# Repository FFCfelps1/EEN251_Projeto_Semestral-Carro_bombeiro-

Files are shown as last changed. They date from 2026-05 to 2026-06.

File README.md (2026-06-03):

# 🚒 EEN251 — Carro de Bombeiro Teleoprado

> **Disciplina:** EEN251 — Projeto Integrador de Sistemas Embarcados  
> **Semestre:** 1º Semestre / 2026  
> **Data de início:** Março de 2026

---

## Sumário

1. [Integrantes e Responsabilidades](#1-integrantes-e-responsabilidades)
2. [Descrição Geral do Projeto](#2-descrição-geral-do-projeto)
3. [Objetivos](#3-objetivos)
4. [Estrutura do Repositório](#4-estrutura-do-repositório)
5. [Materiais e Componentes](#5-materiais-e-componentes)
6. [Arquitetura do Sistema](#6-arquitetura-do-sistema)
7. [Pinagem e Conexões](#7-pinagem-e-conexões)
8. [Firmware — Descrição e Fluxograma de Estados](#8-firmware--descrição-e-fluxograma-de-estados)
9. [Convenção de Commits](#9-convenção-de-commits)
10. [Política de Tags e Versões](#10-política-de-tags-e-versões)
11. [Cronograma](#11-cronograma)
12. [Orçamento Total Estimado](#12-orçamento-total-estimado)
13. [Referências Bibliográficas](#13-referências-bibliográficas)

---

## 1. Integrantes e Responsabilidades

| Nome | RA | Função Principal |
|---|----|---|
| Felipe Fazio da Costa | 23.00055-4 | Firmware do Receptor (Pico RX) — motores e bomba |
| João Gabriel Fioruci Roberto | 23.00617-0 | Firmware do Transmissor (Pico TX) — controle RF |
| Gabriel Rodrigues Marques | 23.00578-5 | Hardware — montagem do chassi e fiação |
| Fábio Sadao Sato | 22.00984-0 | Integração do sistema e documentação |

---

## Resumo

Este relatório descreve o desenvolvimento de um protótipo de carro de bombeiro teleoprado utilizando microcontroladores Raspberry Pi Pico e comunicação via rádio frequência (NRF24L01). O sistema integra tração 4WD, sistema de combate a incêndio por bomba d'água e monitoramento de nível de reservatório. Foram aplicados conceitos de sistemas embarcados, comunicação sem fio e controle de periféricos via PWM. Os resultados demonstram a eficácia da plataforma RP2040 em aplicações de controle em tempo real e teleoperação robusta.

**Palavras-chave**: Raspberry Pi Pico. NRF24L01. MicroPython. Carro de Bombeiro. Sistemas Embarcados.

## Abstract

This report describes the development of a teleoperated fire truck prototype using Raspberry Pi Pico microcontrollers and radio frequency communication (NRF24L01). The system integrates 4WD traction, a water pump fire suppression system, and reservoir level monitoring. Concepts of embedded systems, wireless communication, and peripheral control via PWM were applied. The results demonstrate the effectiveness of the RP2040 platform in real-time control applications and robust teleoperation.

**Keywords**: Raspberry Pi Pico. NRF24L01. MicroPython. Fire Truck. Embedded Systems.

---

## 2. Descrição Geral do Projeto

O projeto consiste no desenvolvimento de um veículo robótico em escala inspirado em um caminhão de bombeiro, capaz de se locomover de maneira teleoprada por meio de comunicação sem fio RF 2.4 GHz (módulo NRF24L01). O veículo é dotado de tração 4WD com quatro motores DC controlados por dois módulos L298N, uma mini bomba d'água acionável remotamente, e um reservatório de água com sensor de nível que alerta o operador quando a água estiver baixa.

O sistema é dividido em dois blocos principais:

- **Transmissor (controle remoto):** baseado em um Raspberry Pi Pico com joystick analógico, botões e display OLED SSD1306, responsável por capturar os comandos do operador e enviá-los via NRF24L01.
- **Receptor (carro):** baseado em um segundo Raspberry Pi Pico que recebe os pacotes RF, interpreta os comandos e aciona os motores, a bomba e os alertas de nível.

Todo o firmware é desenvolvido em **MicroPython**, aproveitando a plataforma Raspberry Pi Pico (microcontrolador RP2040).

---

## 3. Objetivos

O objetivo geral deste trabalho é projetar e construir um veículo robótico controlado remotamente via radiofrequência, capaz de realizar manobras de locomoção e acionamento de uma bomba d'água, com monitoramento de status em tempo real.

### 3.1 Objetivos Específicos

- Implementação de comunicação bidirecional robusta entre controle e veículo;
- Controle de tração diferencial (tank drive) para quatro motores;
- Sistema de alerta de nível de água com indicadores visuais e sonoros;
- Desenvolvimento de firmware em MicroPython para a plataforma Raspberry Pi Pico.

---

## 4. Estrutura do Repositório

```
EEN251_Projeto_Semestral(Carro_bombeiro)/
│
├── docs/                        # Documentação HTML do projeto
│   ├── index.html               # Página principal (abas: Requisitos + Diagramas)
│   ├── diagrama_blocos.html     # Diagrama de blocos standalone (legado)
│   └── diagrama_blocos.md       # Diagrama de blocos em Markdown
│
├── firmware/                    # Código MicroPython (a ser criado)
│   ├── tx/                      # Firmware do transmissor (Pico TX)
│   │   └── main.py
│   └── rx/                      # Firmware do receptor (Pico RX)
│       └── main.py
│
├── hardware/                    # Arquivos de hardware (a ser criado)
│   ├── esquematico.pdf
│   └── lista_materiais.csv
│
├── index.html                   # Redirecionamento para docs/index.html
└── README.md                    # Este arquivo
```

---

## 5. Materiais e Componentes

| Qtd | Componente | Finalidade | Preço Est. (R$) |
|-----|---|---|:---:|
| 2 | Raspberry Pi Pico (RP2040) | Controlador central — TX e RX | 35,00 cada |
| 4 | Motor DC 3–6 V com caixa de redução (TT Motor) | Tração 4WD do veículo | 8,00 cada |
| 2 | Módulo L298N (ponte H dupla) | Driver de corrente para os motores | 15,00 cada |
| 2 | Módulo NRF24L01 (PA+LNA opcional) | Comunicação RF 2.4 GHz | 12,00 cada |
| 1 | Mini bomba d'água submersa 3–6 V | Jato d'água do caminhão | 18,00 |
| 1 | Módulo relé 5 V (1 canal) | Chaveamento de corrente da bomba | 6,00 |
| 1 | Sensor de nível d'água (resistivo/capacitivo) | Monitorar volume no reservatório | 5,00 |
| 1 | Chassi 4WD em acrílico ou MDF | Estrutura física do veículo | 45,00 |
| 1 | Bateria LiPo 3,7 V 1000 mAh (18650) | Alimentação do transmissor | 25,00 |
| 1 | Pack 2S 18650 (7,4 V ~2000 mAh) | Alimentação principal do carro | 40,00 |
| 1 | Módulo redutor DC-DC (MP1584 ou LM2596) | Regular 7,4 V → 5 V | 8,00 |
| 1 | Joystick analógico duplo eixo (KY-023) | Controle direcional (X/Y) | 12,00 |
| 2 | Push button (6 mm) | Ativar bomba / parada de emergência | 1,00 cada |
| 1 | Reservatório plástico (~100–200 mL) | Tanque de água do caminhão | 10,00 |
| 1 | Protoboard ou PCB de prototipagem | Prototipagem do circuito | 15,00 |
| — | Jumpers, fios, resistores, LEDs, buzzer, suportes | Conexões e indicadores | 20,00 |

**Total estimado: R$ 362,00**

---

## 6. Arquitetura do Sistema

```
[Joystick X/Y + Botões]
        │
        ▼
  Pico TX — leitura ADC/GPIO (~20 ms)
        │
        ▼
  Monta pacote: { vel_esq, vel_dir, bomba, stop }  (6 bytes)
        │
        ▼
  NRF24L01 TX ──[ RF 2,4 GHz · Enhanced ShockBurst ]──▶ NRF24L01 RX
                                                               │
                                               Pico RX — decodifica pacote
                                                               │
                              ┌────────────────┬──────────────┘
                              ▼                ▼              ▼
                       L298N #1           L298N #2        GPIO Relé
                    (Motor 1 e 2)       (Motor 3 e 4)     (Bomba)
```

**Mapeamento Tank Drive:**
```
vel_esq = Y + X
vel_dir = Y − X
```
Onde Y = eixo vertical (avanço/recuo) e X = eixo horizontal (giro). Valores limitados a [−100, +100].

---

## 7. Pinagem e Conexões

### Receptor — Raspberry Pi Pico (RX)

| Pino | GPIO | Periférico | Sinal | Obs. |
|---|:----:|---|---|---|
| GP0 | 0 | L298N | IN1 | Direção Motor Esq |
| GP1 | 1 | L298N | IN2 | Direção Motor Esq |
| GP2 | 2 | L298N | IN3 | Direção Motor Dir |
| GP3 | 3 | L298N | IN4 | Direção Motor Dir |
| GP4 | 4 | NRF24L01 | MISO (SPI0) | Dados entrada |
| GP5 | 7 | NRF24L01 | CSn | Chip Select |
| GP6 | 4 | NRF24L01 | SCK (SPI0) | Clock SPI |
| GP7 | 11 | NRF24L01 | MOSI (SPI0) | Dados saída |
| GP8 | 29 | Relé Bomba | Sinal | Ativa bomba |
| GP9 | 11 | L298N | ENA (PWM) | Vel. Motor Esq |
| GP10 | 12 | L298N | ENB (PWM) | Vel. Motor Dir |
| GP12 | 6 | NRF24L01 | CE | Chip Enable |
| GP13 | 32 | LED Indicador | GPIO OUT | Status sinal |
| GP22 | 34 | Sensor Nível (D) | GPIO IN | Alerta digital |
| GP27 | 31 | Sensor Nível (A) | ADC1 | Leitura analógica |

### Transmissor — Raspberry Pi Pico (TX)

| Pino | GPIO | Periférico | Sinal | Obs. |
|---|:----:|---|---|---|
| GP0 | 0 | Display OLED | I2C SDA | Dados I2C |
| GP1 | 1 | Display OLED | I2C SCL | Clock I2C |
| GP4 | 6 | NRF24L01 | MISO (SPI0) | Dados entrada |
| GP5 | 7 | NRF24L01 | CSn | Chip Select |
| GP6 | 4 | NRF24L01 | SCK (SPI0) | Clock SPI |
| GP7 | 5 | NRF24L01 | MOSI (SPI0) | Dados saída |
| GP9 | 9 | NRF24L01 | CE | Chip Enable |
| GP19 | 19 | Botão Bomba | GPIO IN | Pull-up interno |
| GP26 | 32 | Joystick Y | ADC1 | Eixo vertical |
| GP27 | 31 | Joystick X | ADC0 | Eixo horizontal |

> ⚠️ **Atenção:** O NRF24L01 opera em **3,3 V**. Nunca conecte o VCC ao pino 5V.

---

## 8. Firmware — Descrição e Fluxograma de Estados

### Transmissor (Pico TX) — loop de ~20 ms
1. Lê ADC do joystick (0–65535) → mapeia para −100…+100 com zona morta central.
2. Lê botões (pull-up; 0 = pressionado).
3. Calcula `vel_esq` e `vel_dir` (tank drive).
4. Monta pacote de 6 bytes e transmite via NRF24L01 PTX com ACK.

### Receptor (Pico RX) — duas tarefas cooperativas
- **Tarefa RF (alta prioridade):** aguarda IRQ do NRF24L01, decodifica campos e aplica PWM/GPIO imediatamente.
- **Tarefa Sensor (baixa prioridade):** lê ADC do sensor de nível a cada 500 ms; aciona LED e buzzer se abaixo do limiar.
- **Watchdog:** desliga todos os motores e bomba se nenhum pacote válido chegar em 500 ms (failsafe).

---

## 9. Convenção de Commits

Este projeto adota o padrão **[Conventional Commits](https://www.conventionalcommits.org/)** para manter um histórico claro e geração automática de changelogs.

### Formato

```
<tipo>(<escopo>): <descrição curta>

[corpo opcional — explica o contexto e motivação da mudança]

[rodapé opcional — ex.: Refs #issue, BREAKING CHANGE: ...]
```

### Tipos permitidos

| Tipo | Quando usar |
|---|---|
| `feat` | Nova funcionalidade no firmware ou na documentação |
| `fix` | Correção de bug no firmware ou na lógica do sistema |
| `docs` | Alterações apenas em documentação (README, HTML, Markdown) |
| `style` | Formatação, identação, espaços — sem mudança de lógica |
| `refactor` | Refatoração de código sem adição de feature ou correção de bug |
| `test` | Adição ou modificação de testes |
| `chore` | Tarefas de manutenção: atualizar dependências, configurar ambiente |
| `hw` | Alterações em arquivos de hardware (esquemático, lista de materiais) |
| `perf` | Melhorias de desempenho (ex.: ajuste de PWM, tempo de polling) |

### Escopos sugeridos

| Escopo | Descrição |
|---|---|
| `tx` | Firmware do transmissor |
| `rx` | Firmware do receptor |
| `rf` | Módulo de comunicação NRF24L01 |
| `motor` | Controle de motores / L298N |
| `bomba` | Sistema de bomba e relé |
| `sensor` | Sensor de nível / alertas |
| `docs` | Documentação (HTML, Markdown) |
| `hw` | Hardware e pinagem |
| `ci` | Configurações de CI/CD |

### Exemplos

```
feat(rx): adicionar failsafe com watchdog de 500ms

Se nenhum pacote RF válido for recebido em 500ms, todos os motores
são desligados e a bomba é desativada por segurança.

feat(tx): implementar mapeamento tank drive do joystick

fix(rf): corrigir inicialização do NRF24L01 após reset de hardware

docs(docs): adicionar aba de diagramas de bloco no index.html

hw(rx): atualizar pinagem do L298N #2 para GP16–GP21

chore: adicionar .gitignore para arquivos de ambiente MicroPython

style(tx): formatar indentação e remover espaços extras
```

### Regras gerais

- A **descrição curta** deve estar em **português**, no **imperativo** e sem ponto final.
  - ✅ `feat(rx): adicionar leitura do sensor de nível`
  - ❌ `feat(rx): Adicionei a leitura do sensor de nível.`
- Limite a linha do cabeçalho a **72 caracteres**.
- Use o corpo para explicar **o quê** e **por quê**, não o como.
- Commits com `BREAKING CHANGE:` no rodapé indicam mudanças incompatíveis com versões anteriores.

---

## 10. Política de Tags e Versões

O projeto utiliza **[Semantic Versioning (SemVer)](https://semver.org/)** no formato `vMAJOR.MINOR.PATCH`.

### Regras de versionamento

| Componente | Quando incrementar |
|---|---|
| **MAJOR** | Mudança incompatível com versão anterior — ex.: alteração no formato do pacote RF que quebra compatibilidade TX↔RX |
| **MINOR** | Nova funcionalidade adicionada de forma retrocompatível — ex.: novo campo no pacote, novo modo de operação |
| **PATCH** | Correção de bug retrocompatível — ex.: ajuste de deadzone, correção de inicialização |

### Estrutura de tags

```
v<MAJOR>.<MINOR>.<PATCH>[-<pre-release>]

Exemplos:
  v0.1.0          — primeira entrega funcional (RF + motores)
  v0.2.0          — integração da bomba e sensor de nível
  v0.2.1          — correção de bug no failsafe
  v1.0.0          — sistema validado e aprovado para apresentação
  v1.0.0-rc.1     — release candidate antes da apresentação final
```

### Milestones de versão planejadas

| Tag | Semana | Descrição |
|-----|:---:|---|
| `v0.1.0` | 5–6 | Comunicação RF funcionando — TX envia, RX recebe |
| `v0.2.0` | 7–8 | Controle de motores via PWM funcional |
| `v0.3.0` | 9–10 | Bomba, relé e sensor de nível integrados |
| `v0.4.0` | 11–12 | Sistema integrado com failsafe e watchdog |
| `v1.0.0-rc.1` | 13–14 | Release candidate — ajustes e calibração |
| `v1.0.0` | 15–16 | Versão final — apresentação |

### Como criar uma tag

```bash
# Criar tag anotada (recomendado)
git tag -a v0.1.0 -m "feat: primeira versão funcional da comunicação RF"

# Enviar tag para o repositório remoto
git push origin v0.1.0

# Enviar todas as tags de uma vez
git push origin --tags
```

### Branches

| Branch | Propósito |
|---|---|
| `main` | Código estável e testado — apenas merges via PR |
| `develop` | Branch de integração contínua |
| `feat/<nome>` | Novas funcionalidades — ex.: `feat/sensor-nivel` |
| `fix/<nome>` | Correções de bug — ex.: `fix/failsafe-timeout` |
| `hw/<nome>` | Alterações de hardware — ex.: `hw/esquematico-v2` |
| `docs/<nome>` | Atualizações de documentação |

---

## 11. Cronograma

| Semana | Período | Etapa | Responsável | Status |
|:---:|---|---|---|:---:|
| 1–2 | 11/03 – 22/03 | Levantamento de requisitos, aquisição de componentes | Todos | ⏳ Pendente |
| 3–4 | 23/03 – 05/04 | Montagem do chassi 4WD e fiação dos motores + L298N | [Nome 3] | ⏳ Pendente |
| 5–6 | 06/04 – 19/04 | Configuração e teste da comunicação RF (NRF24L01 + Pico) | [Nome 2] | ⏳ Pendente |
| 7–8 | 20/04 – 03/05 | Firmware do receptor: controle de motores via PWM | [Nome 1] | ⏳ Pendente |
| 9–10 | 04/05 – 17/05 | Integração da bomba d'água, relé e sensor de nível | [Nome 1] | ⏳ Pendente |
| 11–12 | 18/05 – 31/05 | Integração geral do sistema e testes de validação | Todos | ⏳ Pendente |
| 13–14 | 01/06 – 14/06 | Ajustes finais, failsafe, calibração de parâmetros | Todos | ⏳ Pendente |
| 15 | 15/06 – 21/06 | Preparação da apresentação e finalização da documentação | [Nome 4] | ⏳ Pendente |
| 16 | 22/06+ | Apresentação final | Todos | ⏳ Pendente |

---

## 12. Orçamento Total Estimado

| Categoria | Itens | Subtotal (R$) |
|---|---|:---:|
| Microcontroladores | 2× Raspberry Pi Pico | 70,00 |
| Motores e driver | 4× Motor DC + 2× L298N | 62,00 |
| Comunicação RF | 2× NRF24L01 | 24,00 |
| Sistema de água | Bomba + Relé + Sensor + Reservatório | 39,00 |
| Alimentação | 2× Baterias + Regulador DC-DC | 73,00 |
| Estrutura | Chassi 4WD + Protoboard | 60,00 |
| Controle | Joystick + Botões | 14,00 |
| Miscelânea | Jumpers, LEDs, buzzer, fios, resistores | 20,00 |
| **TOTAL** | | **R$ 362,00** |

> Preços estimados com base em valores de mercado nacional (Mercado Livre, Baú da Eletrônica, Robocore) em março de 2026.

---

## 13. Referências Bibliográficas

1. **Raspberry Pi Ltd.** *Raspberry Pi Pico Datasheet*. Disponível em: https://datasheets.raspberrypi.com/pico/pico-datasheet.pdf
2. **Raspberry Pi Ltd.** *RP2040 Datasheet*. Disponível em: https://datasheets.raspberrypi.com/rp2040/rp2040-datasheet.pdf
3. **STMicroelectronics.** *L298N Dual Full-Bridge Driver Datasheet*. Disponível em: https://www.st.com/resource/en/datasheet/l298.pdf
4. **Nordic Semiconductor.** *nRF24L01+ Product Specification v1.0*. Disponível em: https://www.nordicsemi.com/products/nrf24l01
5. **MicroPython Project.** *MicroPython Documentation for RP2*. Disponível em: https://docs.micropython.org/en/latest/rp2/quickref.html
6. **micropython-nrf24l01 Library.** Disponível em: https://github.com/micropython/micropython-lib/tree/master/micropython/drivers/radio/nrf24l01
7. **Conventional Commits Specification v1.0.0.** Disponível em: https://www.conventionalcommits.org/pt-br/v1.0.0/
8. **Semantic Versioning 2.0.0.** Disponível em: https://semver.org/lang/pt-BR/

---

*Documento gerado em 11 de março de 2026.*

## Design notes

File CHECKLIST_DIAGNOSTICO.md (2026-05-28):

## CHECKLIST DE DIAGNÓSTICO - NRF24L01

### 1️⃣ VERIFICAÇÃO FÍSICA DE HARDWARE

- [ ] **Capacitor 10µF conectado?**
  - Entre VCC e GND do NRF24L01
  - ISSO É CRÍTICO! Sem ele, o módulo não funciona bem

- [ ] **Fios conectados corretamente?**
  
  **CONTROLE (Pico 1):**
  ```
  NRF24L01          Pico
  ─────────────────────────
  1  GND      →   GND
  2  VCC      →   3.3V (COM CAPACITOR!)
  3  CE       →   GP9
  4  CSN      →   GP5
  5  SCK      →   GP6
  6  MOSI     →   GP7
  7  MISO     →   GP4
  8  IRQ      →   (não conectar)
  ```
  
  **CARRO (Pico 2):**
  ```
  NRF24L01          Pico
  ─────────────────────────
  1  GND      →   GND
  2  VCC      →   3.3V (COM CAPACITOR!)
  3  CE       →   GP12  ← DIFERENTE!
  4  CSN      →   GP5
  5  SCK      →   GP6
  6  MOSI     →   GP7
  7  MISO     →   GP4
  8  IRQ      →   (não conectar)
  ```

- [ ] **Nenhum fio solto ou mal soldado?**
  - Verifique todas as conexões
  - Use multímetro se necessário

### 2️⃣ TESTES DE SOFTWARE

**Ordem recomendada:**

#### PASSO 1: Teste no CONTROLE
```
1. Copie: diagnostico_completo.py → Pico do CONTROLE
2. Execute (deixe rodando por 10s)
3. Veja a saída no console
```

Se o CONTROLE disser **"Módulo não responde"**:
- ❌ Fiação está errada
- ❌ Capacitor não está conectado
- ❌ Módulo NRF24L01 pode estar quebrado

Se o CONTROLE disser **"Envio com sucesso"**:
- ✅ Modulo está OK
- → Vá para PASSO 2

#### PASSO 2: Teste no CARRO
```
1. Copie: diagnostico_completo.py → Pico do CARRO
2. Execute (deixe aguardando)
3. Rode novamente o CONTROLE
```

Se o CARRO disser **"Nenhuma mensagem recebida"**:
- ❌ Receptor pode ter fiação errada
- ❌ Capacitor não está conectado
- ❌ CE está no pino errado (deve ser GP12!)

Se o CARRO disser **"X mensagens recebidas"**:
- ✅ COMUNICAÇÃO FUNCIONANDO!

### 3️⃣ SE AINDA NÃO FUNCIONAR

**Checklist final:**

- [ ] Você colocou um **capacitor 10µF** entre VCC e GND?
- [ ] O **CE do CARRO está em GP12** (não GP9)?
- [ ] Os **pinos SCK/MOSI/MISO** estão iguais nos dois?
- [ ] Os **endereços são iguais?**
  ```
  ADDR_CONTROLE = bytes([0xE7, 0xE7, 0xE7, 0xE7, 0xE7])
  ADDR_CARRO    = bytes([0xC2, 0xC2, 0xC2, 0xC2, 0xC2])
  ```
- [ ] Os **dois Picos estão no CHANNEL 2?**
- [ ] Você **alimenta os Picos corretamente?** (USB ou 5V externo)
- [ ] O **NRF24L01 está alimentado em 3.3V**? (não 5V!)

### 4️⃣ RESULTADO ESPERADO

**CONTROLE console:**
```
[6] TESTE DE ENVIO...
  Enviando: [50, 30, 1, 0]
  ✓ ENVIO COM SUCESSO!
```

**CARRO console:**
```
[6] AGUARDANDO MENSAGENS...
  [1] ✓ RX: X= 50, Y= 30
      ✓ TX: Resposta enviada
```

### ⚡ POTENCIAL PROBLEMA #1: CAPACITOR

**Sintoma:** "send failed" repetido

**Solução:** Adicione capacitor 10µF - 100µF entre VCC e GND do NRF24L01

```
Pico ─[10µF]─ NRF24L01
     GND      VCC   GND
```

### ⚡ POTENCIAL PROBLEMA #2: PIN CE ERRADO

**Sintoma:** CONTROLE: "send failed", CARRO: não recebe nada

**Solução:** Verifique se o CE do CARRO está em **GP12** (não GP9)

### ⚡ POTENCIAL PROBLEMA #3: ALIMENTAÇÃO

**Sintoma:** Módulo não responde

**Solução:** 
- NRF24L01 precisa de **3.3V estável**
- Pico fornece até 500mA pelo pino 3.3V
- Se tem outros componentes, pode ser insuficiente
- Considere usar uma fonte externa 3.3V para o NRF24L01

---

**Qual é a situação?** Você conseguiu executar o `diagnostico_completo.py`?

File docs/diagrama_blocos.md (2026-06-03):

# Diagrama de Blocos — Carro Bombeiro Teleoprado

> Representação detalhada em formato texto e Mermaid do sistema completo.  
> Para renderização visual, abra este arquivo em um visualizador Mermaid (GitHub, VSCode com extensão, Obsidian, etc.)

---

## 1. Diagrama de Blocos Principal (Sistema Completo)

```
╔══════════════════════════════════════════════════════════╗
║              BLOCO TRANSMISSOR (Controle Remoto)         ║
╠══════════════════════════════════════════════════════════╣
║                                                          ║
║   ┌──────────────┐       ┌───────────────────────────┐   ║
║   │ Bateria LiPo │──────▶│  Raspberry Pi Pico (TX)   │   ║
║   │    3,7 V     │       │                           │   ║
║   └──────────────┘       │  ADC0 ◀── Joystick Eixo X │   ║
║                          │  ADC1 ◀── Joystick Eixo Y │   ║
║   ┌──────────────┐       │  GP19 ◀── Botão Bomba     │   ║
║   │ OLED SSD1306 │◀─────▶│  I2C0 ──▶ Display Status  │   ║
║   └──────────────┘       │  SPI0 ──▶ NRF24L01 (TX)   │   ║
║                          └───────────────────────────┘   ║
║                                        │                 ║
║                              NRF24L01 ─┘                 ║
╚══════════════════════════════════════╪═══════════════════╝
                                       │
                               RF 2,4 GHz
                           Enhanced ShockBurst
                                       │
╔══════════════════════════════════════╪═══════════════════╗
║              BLOCO RECEPTOR (Carro Bombeiro)             ║
╠══════════════════════════════════════╪═══════════════════╣
║                              NRF24L01 (RX)               ║
║                                       │ SPI0             ║
║   ┌───────────────┐       ┌───────────▼───────────────┐  ║
║   │  Bateria 2S   │──────▶│  Raspberry Pi Pico (RX)   │  ║
║   │   7,4 V       │       │                           │  ║
║   └───┬───────────┘       │  GP0, 1 ──▶ IN1, IN2 (Mot)│  ║
║       │                   │  GP2, 3 ──▶ IN3, IN4 (Mot)│  ║
║       ▼                   │  GP9, 10──▶ ENA, ENB (PWM)│  ║
║  ┌──────────────┐          │  GP8     ──▶ Relé Bomba   │  ║
║  │ Regulador   │          │  GP27 ADC ◀── Sensor Nív. │  ║
║  │ 7,4V → 5V  │          │  GP22     ◀── Sensor (D)   │  ║
║  └──────┬───────┘          │  GP13     ──▶ LED Status  │  ║
║         │                  └───────────────────────────┘  ║
║         │                                                  ║
║         ├──────────────────────────────────────────────┐  ║
║         │                                              │  ║
║         ▼                    ▼                         ▼  ║
║   ┌──────────┐        ┌───────────┐            ┌──────────┐║
║   │ Driver   │        │   Relé    │            │  Bomba   │║
║   │  L298N   │        │    5V     │            │ d'água   │║
║   └──┬────┬──┘        └─────┬─────┘            └─────┬────┘║
║      │    │                 │                        │     ║
║      ▼    ▼                 ▼                        ▼     ║
║   Motores Esq        Motores Dir               Jato d'água ║
║   (4WD)              (4WD)                                 ║
║                                                            ║
║                                             ┌─────▼────┐  ║
║                          Sensor Nível ◀─────│Reservat. │  ║
║                                             └──────────┘  ║
╚══════════════════════════════════════════════════════════╝
```

---

## 2. Diagrama Mermaid — Subsistema Transmissor

```mermaid
graph TD
    BAT_TX["🔋 Bateria LiPo\n3,7V"]
    PICO_TX["⚙️ Raspberry Pi Pico TX\n(RP2040)"]
    JOY_X["🕹️ Joystick — Eixo X\n(ADC0 / GP27)"]
    JOY_Y["🕹️ Joystick — Eixo Y\n(ADC1 / GP26)"]
    BTN1["🔴 Botão Bomba\n(GP19 — pull-up)"]
    OLED["🖥️ Display OLED\n(I2C0 / GP0, 1)"]
    NRF_TX["📡 NRF24L01\n(SPI0 | PTX mode)"]
    RF["≋≋≋ RF 2,4 GHz ≋≋≋\nEnhanced ShockBurst"]

    BAT_TX -->|"3,3V (via Pico onboard)"| PICO_TX
    JOY_X -->|"ADC 0–3,3V"| PICO_TX
    JOY_Y -->|"ADC 0–3,3V"| PICO_TX
    BTN1 -->|"GPIO LOW = pressionado"| PICO_TX
    PICO_TX -->|"I2C SDA/SCL"| OLED
    PICO_TX -->|"SPI: SCK/MOSI/MISO/CS/CE"| NRF_TX
    NRF_TX -->|"Pacote 4 bytes @ ~12Hz"| RF
```

---

## 3. Diagrama Mermaid — Subsistema Receptor

```mermaid
graph TD
    BAT_RX["🔋 Bateria 2S\n7,4V / 2000mAh"]
    REG["⚡ Regulador DC-DC\n7,4V → 5V (MP1584)"]
    PICO_RX["⚙️ Raspberry Pi Pico RX\n(RP2040)"]
    RF_IN["≋≋≋ RF 2,4 GHz ≋≋≋"]
    NRF_RX["📡 NRF24L01\n(SPI0 | PRX mode)"]
    L298N["🔧 Driver L298N\n(Motores)"]
    M1["⚙ Motor Esq.\nDiant + Tras"]
    M2["⚙ Motor Dir.\nDiant + Tras"]
    RELAY["🔌 Relé 5V\n(Bomba)"]
    PUMP["💧 Mini Bomba d'água\n3–6V DC"]
    SENSOR_A["📊 Sensor Nível (A)\nADC / GP27"]
    SENSOR_D["🚨 Alerta Nível (D)\nGPIO / GP22"]
    LED["💡 LED Indicador\nStatus RF / GP13"]

    BAT_RX -->|"7,4V"| REG
    REG -->|"5V"| L298N
    REG -->|"5V"| RELAY
    REG -->|"3,3V via Pico VSYS"| PICO_RX

    RF_IN -->|"pacote recebido"| NRF_RX
    NRF_RX -->|"SPI: interrupção IRQ"| PICO_RX

    PICO_RX -->|"PWM ENA/ENB + IN1–IN4"| L298N
    L298N --> M1
    L298N --> M2

    PICO_RX -->|"GPIO OUT / GP8"| RELAY
    RELAY -->|"5V chaveado"| PUMP
    
    SENSOR_A -->|"analog"| PICO_RX
    SENSOR_D -->|"digital"| PICO_RX
    PICO_RX -->|"GPIO OUT"| LED
```

---

## 4. Diagrama de Estados — Receptor (Firmware)

```mermaid
stateDiagram-v2
    [*] --> INICIALIZANDO

    INICIALIZANDO --> AGUARDANDO_RF : configuração concluída

    AGUARDANDO_RF --> RECEBENDO_PACOTE : IRQ NRF24L01
    AGUARDANDO_RF --> FAILSAFE : timeout > 500ms

    RECEBENDO_PACOTE --> STOP : stop == 1
    RECEBENDO_PACOTE --> MOVENDO : stop == 0

    MOVENDO --> BOMBA_ON : bomba == 1
    MOVENDO --> BOMBA_OFF : bomba == 0
    BOMBA_ON --> AGUARDANDO_RF
    BOMBA_OFF --> AGUARDANDO_RF

    STOP --> AGUARDANDO_RF

    FAILSAFE --> AGUARDANDO_RF : pacote válido recebido

    note right of FAILSAFE
        Todos os motores parados
        Bomba desligada
        LED piscando
    end note

    note right of MOVENDO
        PWM aplicado nos L298N
        Velocidade diferencial
        por lado (tank drive)
    end note
```

---

## 5. Estrutura do Pacote RF

```
┌─────────┬──────────────────────────────────────────────────┐
│  Byte   │  Descrição                                        │
├─────────┼──────────────────────────────────────────────────┤
│    0    │  vel_esq  — int8  — velocidade lado esq. (−100..+100) │
│    1    │  vel_dir  — int8  — velocidade lado dir. (−100..+100) │
│    2    │  bomba    — uint8 — 0=OFF, 1=ON                   │
│    3    │  stop     — uint8 — 0=normal, 1=parada emergência │
└─────────┴──────────────────────────────────────────────────┘
Tamanho total: 4 bytes (campo fixo — NRF24L01 static payload)
Taxa: ~12 pacotes/segundo (conforme configurado no firmware)
```

---

## 6. Diagrama de Alimentação

```
Bateria 2S (7,4V)
       │
       ├──[Regulador DC-DC MP1584]──→ 5V ──┬── L298N (VCC lógico)
       │                                   ├── Relé 5V (bobina)
       │                                   └── Pico (VSYS → regulador 3,3V interno)
       │                                            │
       │                                           3,3V ──── NRF24L01 VCC
       │
       └──[Direto 7,4V]──→ L298N (pino VS — potência dos motores)
                           (corrente pico ~2A por driver, 4A total)
```

---

*Arquivo gerado em 11 de março de 2026 — EEN251 Projeto Semestral.*

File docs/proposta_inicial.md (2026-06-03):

# EEN251 — Projeto Semestral: Carro de Bombeiro Teleoprado

> **Disciplina:** EEN251 — Projeto Integrador de Sistemas Embarcados  
> **Semestre:** 1º Semestre / 2026  
> **Data de início:** Março de 2026

---

## Sumário

1. [Integrantes e Responsabilidades](#1-integrantes-e-responsabilidades)
2. [Descrição Geral do Projeto](#2-descrição-geral-do-projeto)
3. [Objetivos](#3-objetivos)
4. [Materiais e Componentes](#4-materiais-e-componentes)
5. [Arquitetura do Sistema](#5-arquitetura-do-sistema)
6. [Diagrama de Blocos](#6-diagrama-de-blocos)
7. [Pinagem e Conexões](#7-pinagem-e-conexões)
8. [Firmware — Descrição e Fluxograma de Estados](#8-firmware--descrição-e-fluxograma-de-estados)
9. [Cronograma](#9-cronograma)
10. [Orçamento Total Estimado](#10-orçamento-total-estimado)
11. [Riscos e Limitações](#11-riscos-e-limitações)
12. [Referências Bibliográficas](#12-referências-bibliográficas)

---

## 1. Integrantes e Responsabilidades

| Nome | RA | Função Principal |
|---|----|---|
| Felipe Fazio da Costa | 23.00055-4 | Firmware do Receptor (Pico RX) — motores e bomba |
| João Gabriel Fioruci Roberto | 23.00617-0 | Firmware do Transmissor (Pico TX) — controle RF |
| Gabriel Rodrigues Marques | 23.00578-5 | Hardware — montagem do chassi e fiação |
| Fábio Sadao Sato | 22.00984-0 | Integração do sistema e documentação |

---

## 2. Descrição Geral do Projeto

O projeto consiste no desenvolvimento de um veículo robótico em escala inspirado em um caminhão de bombeiro, capaz de se locomover de maneira teleoprada por meio de comunicação sem fio RF 2.4 GHz (módulo NRF24L01). O veículo é dotado de tração 4WD com quatro motores DC controlados por dois módulos L298N, uma mini bomba d'água acionável remotamente, e um reservatório de água com sensor de nível que alerta o operador quando a água estiver baixa.

O sistema é dividido em dois blocos principais:

- **Transmissor (controle remoto):** baseado em um Raspberry Pi Pico com joystick analógico, botões e display OLED SSD1306, responsável por capturar os comandos do operador e enviá-los via NRF24L01.
- **Receptor (carro):** baseado em um segundo Raspberry Pi Pico que recebe os pacotes RF, interpreta os comandos e aciona os motores, a bomba e os alertas de nível.

Todo o firmware é desenvolvido em MicroPython, aproveitando a plataforma Raspberry Pi Pico (microcontrolador RP2040) como base de hardware.

---

## 3. Objetivos

O objetivo geral deste trabalho é projetar e construir um veículo robótico controlado remotamente via radiofrequência, capaz de realizar manobras de locomoção e acionamento de uma bomba d'água, com monitoramento de status em tempo real.

### 3.1 Objetivos Específicos

- Implementação de comunicação bidirecional robusta entre controle e veículo;
- Controle de tração diferencial (tank drive) para quatro motores;
- Sistema de alerta de nível de água com indicadores visuais e sonoros;
- Desenvolvimento de firmware em MicroPython para a plataforma Raspberry Pi Pico.

---

## 4. Materiais e Componentes

| Qtd | Componente | Finalidade | Preço Est. (R$) |
|-----|---|---|:---:|
| 2 | Raspberry Pi Pico (RP2040) | Controlador central — TX e RX | 35,00 cada |
| 4 | Motor DC 3–6 V com caixa de redução (TT Motor) | Tração 4WD do veículo | 8,00 cada |
| 2 | Módulo L298N (ponte H dupla) | Driver de corrente para os motores | 15,00 cada |
| 2 | Módulo NRF24L01 (PA+LNA opcional) | Comunicação RF 2.4 GHz | 12,00 cada |
| 1 | Mini bomba d'água submersa 3–6 V | Jato d'água do caminhão | 18,00 |
| 1 | Módulo relé 5 V (1 canal) | Chaveamento de corrente da bomba | 6,00 |
| 1 | Sensor de nível d'água (resistivo/capacitivo) | Monitorar volume no reservatório | 5,00 |
| 1 | Chassi 4WD em acrílico ou MDF | Estrutura física do veículo | 45,00 |
| 1 | Bateria LiPo 3,7 V 1000 mAh (18650) | Alimentação do transmissor | 25,00 |
| 1 | Pack 2S 18650 (7,4 V ~2000 mAh) | Alimentação principal do carro | 40,00 |
| 1 | Módulo redutor DC-DC (MP1584 ou LM2596) | Regular 7,4 V → 5 V para periféricos | 8,00 |
| 1 | Joystick analógico duplo eixo (KY-023) | Controle direcional (X/Y) | 12,00 |
| 2 | Push button (6 mm) | Ativar bomba / parada de emergência | 1,00 cada |
| 1 | Reservatório plástico (aprox. 100–200 mL) | Tanque de água do caminhão | 10,00 |
| 1 | Protoboard ou PCB de prototipagem | Prototipagem do circuito | 15,00 |
| — | Jumpers, fios, resistores, LEDs, buzzer, suportes | Conexões e indicadores | 20,00 |

---

## 5. Arquitetura do Sistema

O sistema é composto por dois subsistemas independentes que se comunicam exclusivamente via RF:

**Subsistema Transmissor** — opera de forma autônoma lendo os sensores de entrada (joystick e botões), convertendo-os em pacotes de dados e transmitindo-os pelo NRF24L01 em modo PTX (*Primary TX*). O Pico TX fica em loop contínuo lendo ADC e GPIO, monta o pacote e envia a cada ~20 ms (~50 Hz de atualização).

**Subsistema Receptor** — o Pico RX opera em modo PRX (*Primary RX*), aguardando pacotes. Ao receber um pacote válido, decodifica os campos (velocidade_esquerda, velocidade_direita, bomba_on) e aciona os respectivos periféricos via PWM (motores) e GPIO digital (relé). Em paralelo, a leitura do sensor de nível é feita periodicamente pelo ADC, e alertas são acionados se o nível cair abaixo de um limiar pré-definido.

A comunicação RF utiliza protocolo `Enhanced ShockBurst` nativo do NRF24L01, com confirmação automática de recebimento (ACK), minimizando a necessidade de tratamento de erros no firmware.

---

## 6. Diagrama de Blocos

### 6.1 Visão Geral do Sistema

```mermaid
graph LR
    subgraph TX["BLOCO TRANSMISSOR — Controle Remoto"]
        direction TB
        BAT_TX["Bateria\n3,7V LiPo"]
        PICO_TX["Raspberry Pi Pico\n(Controlador TX)"]
        JOY["Joystick Analógico\n(ADC X / Y)"]
        BTN_PUMP["Botão\nAtivar Bomba"]
        BTN_STOP["Botão\nStop / Emergência"]
        NRF_TX["Módulo NRF24L01\n(SPI — PTX)"]

        BAT_TX --> PICO_TX
        JOY -->|ADC| PICO_TX
        BTN_PUMP -->|GPIO| PICO_TX
        BTN_STOP -->|GPIO| PICO_TX
        PICO_TX -->|SPI| NRF_TX
    end

    subgraph RX["BLOCO RECEPTOR — Carro Bombeiro"]
        direction TB
        BAT_RX["Bateria\n7,4V 2S"]
        REG["Regulador DC-DC\n7,4V → 5V / 3,3V"]
        PICO_RX["Raspberry Pi Pico\n(Controlador RX)"]
        NRF_RX["Módulo NRF24L01\n(SPI — PRX)"]
        L298N_A["L298N #1\n(lado esquerdo)"]
        L298N_B["L298N #2\n(lado direito)"]
        M1["Motor 1\n(Diant. Esq.)"]
        M2["Motor 2\n(Tras. Esq.)"]
        M3["Motor 3\n(Diant. Dir.)"]
        M4["Motor 4\n(Tras. Dir.)"]
        RELAY["Relé 5V"]
        PUMP["Mini Bomba\nd'água"]
        RESERV["Reservatório\nd'água"]
        SENSOR["Sensor de Nível\n(ADC)"]
        LED["LED\nAlerta"]
        BUZZ["Buzzer\nAlerta"]

        BAT_RX --> REG
        REG -->|5V| L298N_A
        REG -->|5V| L298N_B
        REG -->|5V| RELAY
        REG -->|3,3V| PICO_RX
        NRF_RX -->|SPI| PICO_RX
        PICO_RX -->|PWM + GPIO| L298N_A
        PICO_RX -->|PWM + GPIO| L298N_B
        L298N_A --> M1
        L298N_A --> M2
        L298N_B --> M3
        L298N_B --> M4
        PICO_RX -->|GPIO| RELAY
        RELAY --> PUMP
        PUMP -->|pressuriza| RESERV
        RESERV -->|nível| SENSOR
        SENSOR -->|ADC| PICO_RX
        PICO_RX -->|GPIO| LED
        PICO_RX -->|GPIO| BUZZ
    end

    NRF_TX -->|"RF 2,4 GHz\n(Enhanced ShockBurst)"| NRF_RX
```

### 6.2 Fluxo de Comunicação RF

```
[Joystick X/Y + Botões]
        |
        v
  Pico TX: leitura ADC/GPIO (20 ms)
        |
        v
  Monta pacote: { vel_esq, vel_dir, bomba }  (6 bytes)
        |
        v
  NRF24L01 TX  ----[ RF 2,4 GHz ]---->  NRF24L01 RX
                                               |
                                               v
                                   Pico RX: decodifica pacote
                                               |
                          +--------------------+--------------------+
                          |                    |                    |
                          v                    v                    v
                   PWM L298N #1        PWM L298N #2           GPIO Relé
                  (Motor 1 e 2)       (Motor 3 e 4)           (Bomba)
```

---

## 7. Pinagem e Conexões

### 7.1 Receptor — Raspberry Pi Pico (RX)

| Pino | GPIO | Periférico | Sinal | Obs. |
|---|:----:|---|---|---|
| GP0 | 0 | L298N | IN1 | Direção Motor Esq |
| GP1 | 1 | L298N | IN2 | Direção Motor Esq |
| GP2 | 2 | L298N | IN3 | Direção Motor Dir |
| GP3 | 3 | L298N | IN4 | Direção Motor Dir |
| GP4 | 4 | NRF24L01 | MISO (SPI0) | Dados entrada |
| GP5 | 7 | NRF24L01 | CSn | Chip Select |
| GP6 | 4 | NRF24L01 | SCK (SPI0) | Clock SPI |
| GP7 | 11 | NRF24L01 | MOSI (SPI0) | Dados saída |
| GP8 | 29 | Relé Bomba | Sinal | Ativa bomba |
| GP9 | 11 | L298N | ENA (PWM) | Vel. Motor Esq |
| GP10 | 12 | L298N | ENB (PWM) | Vel. Motor Dir |
| GP12 | 6 | NRF24L01 | CE | Chip Enable |
| GP13 | 32 | LED Indicador | GPIO OUT | Status sinal |
| GP22 | 34 | Sensor Nível (D) | GPIO IN | Alerta digital |
| GP27 | 31 | Sensor Nível (A) | ADC1 | Leitura analógica |

### 7.2 Transmissor — Raspberry Pi Pico (TX)

| Pino | GPIO | Periférico | Sinal | Obs. |
|---|:----:|---|---|---|
| GP0 | 0 | Display OLED | I2C SDA | Dados I2C |
| GP1 | 1 | Display OLED | I2C SCL | Clock I2C |
| GP4 | 6 | NRF24L01 | MISO (SPI0) | Dados entrada |
| GP5 | 7 | NRF24L01 | CSn | Chip Select |
| GP6 | 4 | NRF24L01 | SCK (SPI0) | Clock SPI |
| GP7 | 5 | NRF24L01 | MOSI (SPI0) | Dados saída |
| GP9 | 9 | NRF24L01 | CE | Chip Enable |
| GP19 | 19 | Botão Bomba | GPIO IN | Pull-up interno |
| GP26 | 32 | Joystick Y | ADC1 | Eixo vertical |
| GP27 | 31 | Joystick X | ADC0 | Eixo horizontal |

> **Nota:** O NRF24L01 opera em 3,3 V. Os pinos GPIO do Raspberry Pi Pico também operam em 3,3 V — compatibilidade direta, sem necessidade de divisor de tensão.

---

## 8. Firmware — Descrição e Fluxograma de Estados

### 8.1 Transmissor (Pico TX)

O firmware do transmissor opera em loop contínuo com período de ~20 ms:

1. Lê os valores analógicos do joystick (ADC0 e ADC1), mapeando a faixa 0–65535 para –100 a +100 (porcentagem de velocidade).
2. Aplica uma zona morta central (deadzone) para evitar movimento indesejado quando o joystick está na posição de repouso.
3. Lê o estado dos botões (pull-up interno; nível lógico 0 = pressionado).
4. Calcula os valores de velocidade para o lado esquerdo e direito com base no mapeamento *tank drive* (Y = avanço/recuo, X = giro).
5. Monta o pacote de 6 bytes: `[ vel_esq (int8), vel_dir (int8), bomba (uint8), stop (uint8), reservado, reservado ]`.
6. Transmite o pacote via NRF24L01 em modo PTX com ACK habilitado.

### 8.2 Receptor (Pico RX)

O firmware do receptor opera com duas tarefas cooperativas:

- **Tarefa RF (alta prioridade):** aguarda interrupção do NRF24L01 indicando pacote disponível. Ao receber, decodifica os campos e aplica imediatamente os comandos de PWM nos L298N e o sinal no relé.
- **Tarefa Sensor (baixa prioridade):** lê o ADC do sensor de nível a cada 500 ms. Se o valor lido estiver abaixo do limiar configurado, aciona LED e buzzer.
- **Watchdog:** se nenhum pacote RF válido for recebido em 500 ms, todos os motores são desligados (failsafe).

### 8.3 Fluxograma do Firmware — Receptor

```mermaid
flowchart TD
    START([Inicialização]) --> INIT["Configurar:\n- SPI (NRF24L01)\n- GPIO (L298N, Relé, LED, Buzzer)\n- ADC (Sensor Nível)\n- PWM (ENA/ENB L298N)"]
    INIT --> PRX["Habilitar NRF24L01\nem modo PRX"]
    PRX --> LOOP["Loop Principal"]

    LOOP --> RX_CHECK{"Pacote RF\ndisponível?"}

    RX_CHECK -->|"Sim"| PARSE["Decodificar pacote:\nvel_esq, vel_dir, bomba, stop"]
    PARSE --> STOP_CHECK{"stop == 1?"}
    STOP_CHECK -->|"Sim"| STOP_ALL["Parar todos os motores\nDesligar bomba"]
    STOP_CHECK -->|"Não"| APPLY_MOT["Aplicar PWM nos\nL298N #1 e #2"]
    APPLY_MOT --> PUMP_CHECK{"bomba == 1?"}
    PUMP_CHECK -->|"Sim"| RELAY_ON["Ligar relé\n(bomba ativa)"]
    PUMP_CHECK -->|"Não"| RELAY_OFF["Desligar relé\n(bomba inativa)"]
    RELAY_ON --> RESET_WDT["Resetar watchdog"]
    RELAY_OFF --> RESET_WDT
    STOP_ALL --> RESET_WDT

    RX_CHECK -->|"Não"| WDT_CHECK{"Timeout\n> 500 ms?"}
    WDT_CHECK -->|"Sim"| FAILSAFE["FAILSAFE:\nParar motores\nDesligar bomba"]
    WDT_CHECK -->|"Não"| LEVEL_TASK

    RESET_WDT --> LEVEL_TASK

    FAILSAFE --> LEVEL_TASK

    LEVEL_TASK{"Tempo sensor\n>= 500 ms?"}
    LEVEL_TASK -->|"Não"| LOOP
    LEVEL_TASK -->|"Sim"| READ_ADC["Ler ADC\n(Sensor de nível)"]
    READ_ADC --> LEVEL_CHECK{"Nível <\nlimiar?"}
    LEVEL_CHECK -->|"Sim"| ALERT_ON["Acionar LED\ne Buzzer"]
    LEVEL_CHECK -->|"Não"| ALERT_OFF["Desligar LED\ne Buzzer"]
    ALERT_ON --> LOOP
    ALERT_OFF --> LOOP
```

### 8.4 Mapeamento Tank Drive

A conversão do joystick analógico para velocidade diferencial dos motores segue o modelo *tank drive*:

```
vel_esq = Y + X
vel_dir = Y − X
```

Onde Y representa o eixo de avanço/recuo e X o eixo de rotação. Os valores são limitados ao intervalo [−100, +100] e convertidos para duty cycle PWM (0–65535 no RP2040).

---

## 9. Cronograma

| Semana | Período | Etapa | Responsável | Status |
|:---:|---|---|---|:---:|
| 1–2 | 11/03 – 22/03 | Levantamento de requisitos, aquisição de componentes | Todos | Pendente |
| 3–4 | 23/03 – 05/04 | Montagem do chassi 4WD e fiação dos motores + L298N | [Nome 3] | Pendente |
| 5–6 | 06/04 – 19/04 | Configuração e teste da comunicação RF (NRF24L01 + Pico) | [Nome 2] | Pendente |
| 7–8 | 20/04 – 03/05 | Firmware do receptor: controle de motores via PWM | [Nome 1] | Pendente |
| 9–10 | 04/05 – 17/05 | Integração da bomba d'água, relé e sensor de nível | [Nome 1] | Pendente |
| 11–12 | 18/05 – 31/05 | Integração geral do sistema e testes de validação | Todos | Pendente |
| 13–14 | 01/06 – 14/06 | Ajustes finais, failsafe, calibração de parâmetros | Todos | Pendente |
| 15 | 15/06 – 21/06 | Preparação da apresentação e finalização da documentação | [Nome 4] | Pendente |
| 16 | 22/06+ | Apresentação final | Todos | Pendente |

---

## 10. Orçamento Total Estimado

| Categoria | Itens | Subtotal (R$) |
|---|---|:---:|
| Microcontroladores | 2× Raspberry Pi Pico | 70,00 |
| Motores e driver | 4× Motor DC + 2× L298N | 62,00 |
| Comunicação RF | 2× NRF24L01 | 24,00 |
| Sistema de água | Bomba + Relé + Sensor + Reservatório | 39,00 |
| Alimentação | 2× Baterias + Regulador DC-DC | 73,00 |
| Estrutura | Chassi 4WD + Protoboard | 60,00 |
| Controle | Joystick + Botões | 14,00 |
| Miscelânea | Jumpers, LEDs, buzzer, fios, resistores | 20,00 |
| **TOTAL** | | **R$ 362,00** |

> Os preços são estimativas baseadas em valores de mercado nacional (Mercado Livre, Baú da Eletrônica, Robocore) em março de 2026 e podem variar conforme fornecedor e frete.

---

## 11. Riscos e Limitações

- **Alcance do NRF24L01:** em ambiente interno com obstáculos, o alcance efetivo pode ser inferior a 15–20 m. A versão PA+LNA eleva o alcance para ~100 m em campo aberto.
- **Impermeabilização:** os componentes eletrônicos devem ser protegidos contra respingos da bomba d'água. Recomenda-se posicionar a eletrônica distante do bico de saída da bomba.
- **Autonomia da bateria:** com 4 motores + bomba em operação simultânea, a corrente pode ultrapassar 2 A. A bateria 2S deve ter capacidade suficiente (>2000 mAh) para operação de ~20–30 minutos.
- **Aquecimento do L298N:** o L298N possui eficiência de ~70%. Em operação de alta carga, o dissipador de alumônio incluído no módulo pode ser insuficiente — monitorar temperatura em testes prolongados.
- **Latência RF:** o protocolo Enhanced ShockBurst do NRF24L01 adiciona latência de ~1–2 ms por pacote. Para controle em malha aberta (sem encoder), isso é aceitável.
- **Compatibilidade de tensão:** NRF24L01 opera em 3,3 V. O RPi Pico já opera em 3,3 V, mas atenção ao não conectar o VCC do módulo ao pino 5V por engano.
- **Sensor de nível resistivo:** sensores resistivos têm vida útil reduzida pela corrosão dos eletrodos. Para uso prolongado, considerar sensor capacitivo ou optoeletrônico.

---

## 12. Referências Bibliográficas

1. **Raspberry Pi Ltd.** *Raspberry Pi Pico Datasheet*. Disponível em: [https://datasheets.raspberrypi.com/pico/pico-datasheet.pdf](https://datasheets.raspberrypi.com/pico/pico-datasheet.pdf). Acesso em: mar. 2026.

2. **Raspberry Pi Ltd.** *RP2040 Datasheet*. Disponível em: [https://datasheets.raspberrypi.com/rp2040/rp2040-datasheet.pdf](https://datasheets.raspberrypi.com/rp2040/rp2040-datasheet.pdf). Acesso em: mar. 2026.

3. **STMicroelectronics.** *L298N Dual Full-Bridge Driver Datasheet*. Disponível em: [https://www.st.com/resource/en/datasheet/l298.pdf](https://www.st.com/resource/en/datasheet/l298.pdf). Acesso em: mar. 2026.

4. **Nordic Semiconductor.** *nRF24L01+ Product Specification v1.0*. Disponível em: [https://www.nordicsemi.com/products/nrf24l01](https://www.nordicsemi.com/products/nrf24l01). Acesso em: mar. 2026.

5. **MicroPython Project.** *MicroPython Documentation for RP2*. Disponível em: [https://docs.micropython.org/en/latest/rp2/quickref.html](https://docs.micropython.org/en/latest/rp2/quickref.html). Acesso em: mar. 2026.

6. **Micropython-nrf24l01 Library.** Disponível em: [https://github.com/micropython/micropython-lib/tree/master/micropython/drivers/radio/nrf24l01](https://github.com/micropython/micropython-lib/tree/master/micropython/drivers/radio/nrf24l01). Acesso em: mar. 2026.

---

*Documento gerado em 11 de março de 2026.*

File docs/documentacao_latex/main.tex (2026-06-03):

\documentclass[
	12pt,				
	openright,			
	oneside,			
	a4paper,			
	english,			
	brazilian			
	]{abntex2}

% ---
% Pacotes básicos 
% ---
\usepackage{lmodern}			
\usepackage[T1]{fontenc}		
\usepackage[utf8]{inputenc}		
\usepackage{indentfirst}		
\usepackage{color}				
\usepackage{graphicx}			
\usepackage{microtype} 			
\usepackage{listings}			
\usepackage{pdfpages}			
\usepackage{tikz}				% para diagramas de blocos
\usetikzlibrary{shapes,arrows,positioning,calc}
% ---

% Compatibilidade memoir vs abntex2cite
% ---
\renewcommand{\tt}{\normalfont\ttfamily} % Corrige erro de comando \tt obsoleto

% ---
% Configurações de listings para MicroPython
% ---
\definecolor{codegreen}{rgb}{0,0.6,0}
\definecolor{codegray}{rgb}{0.5,0.5,0.5}
\definecolor{codepurple}{rgb}{0.58,0,0.82}
\definecolor{backcolour}{rgb}{0.95,0.95,0.92}

\lstset{
    language=Python,
    backgroundcolor=\color{backcolour},   
    commentstyle=\color{codegreen},
    keywordstyle=\color{magenta},
    numberstyle=\tiny\color{codegray},
    stringstyle=\color{codepurple},
    basicstyle=\ttfamily\footnotesize,
    breakatwhitespace=false,         
    breaklines=true,                 
    captionpos=b,                    
    keepspaces=true,                 
    numbers=left,                    
    numbersep=5pt,                  
    showspaces=false,                
    showstringspaces=false,
    showtabs=false,                  
    tabsize=2,
    extendedchars=true,
    inputencoding=utf8,
    literate={á}{{\'a}}1 {ã}{{\~a}}1 {â}{{\^a}}1 {à}{{\`a}}1 {Á}{{\'A}}1 {Ã}{{\~A}}1 {Â}{{\^A}}1 {À}{{\`A}}1
             {é}{{\'e}}1 {ê}{{\^e}}1 {É}{{\'E}}1 {Ê}{{\^E}}1
             {í}{{\'i}}1 {Í}{{\'I}}1
             {ó}{{\'o}}1 {õ}{{\~o}}1 {ô}{{\^o}}1 {Ó}{{\'O}}1 {Õ}{{\~O}}1 {Ô}{{\^O}}1
             {ú}{{\'u}}1 {Ú}{{\'U}}1
             {ç}{{\c{c}}}1 {Ç}{{\c{C}}}1 {—}{{---}}1 {→}{{$\rightarrow$}}1 {°}{{$^\circ$}}1
}

% ---
% Pacotes de citações
% ---
\usepackage[brazilian,hyperpageref]{backref}
\usepackage[alf,abnt-emphasize=bf]{abntex2cite}	% Citações padrão ABNT

% --- 
% CONFIGURAÇÕES DE PACOTES
% --- 
\renewcommand{\backrefpagesname}{Citado na(s) página(s):~}
\renewcommand{\backref}{}
\renewcommand*{\backrefalt}[4]{
	\ifcase #1 
		Nenhuma citação no texto.
	\or
		Citado na página #2.
	\else
		Citado na página #2.
	\fi}

% ---
% Informações de dados para CAPA e CONTRA CAPA
% ---
\titulo{Projeto Semestral: Carro de Bombeiro Teleoprado}
\autor{Felipe Fazio da Costa, RA: 23.00055-4 \\ João Gabriel Fioruci Roberto, RA: 23.00617-0 \\ Gabriel Rodrigues Marques, RA: 23.00578-5 \\ Fábio Sadao Sato, RA: 22.00984-0}
\local{Brasil}
\data{2026}
\instituicao{%
  Centro Universitário Instituto Mauá de Tecnologia
  \par
  Engenharia de Computação / Eletrônica
  \par
  Disciplina: EEN251 --- Projeto de Sistemas Embarcados}
\tipotrabalho{Relatório Técnico}
\preambulo{Relatório técnico apresentado como requisito parcial para aprovação na disciplina EEN251 --- Projeto Integrador de Sistemas Embarcados do curso de Engenharia.}

% ---
% Configurações de aparência do PDF final
\definecolor{blue}{RGB}{41,5,195}

\hypersetup{
		pdftitle={Projeto Semestral: Carro de Bombeiro Teleoprado}, 
		pdfauthor={Felipe Fazio da Costa, João Gabriel Fioruci Roberto, Gabriel Rodrigues Marques, Fábio Sadao Sato},
    	pdfsubject={Relatório técnico de Projeto Integrador},
	    pdfcreator={LaTeX with abntex2},
		pdfkeywords={abnt}{latex}{pico}{nrf24l01}{carro de bombeiro}, 
		colorlinks=true,       		
    	linkcolor=blue,          	
    	citecolor=blue,        		
    	filecolor=magenta,      		
		urlcolor=blue,
		bookmarksdepth=4
}

% --- 
% Espaçamentos entre linhas e parágrafos 
% --- 
\setlength{\parindent}{1.3cm}
\setlength{\parskip}{0.2cm}  

\makeindex

% ----
\begin{document}
\selectlanguage{brazilian}
\frenchspacing 

% ----------------------------------------------------------
\imprimircapa
\imprimirfolhaderosto

\begin{resumo}
 Este relatório descreve o desenvolvimento de um protótipo de carro de bombeiro teleoprado utilizando microcontroladores Raspberry Pi Pico e comunicação via rádio frequência (NRF24L01). O sistema integra tração 4WD, sistema de combate a incêndio por bomba d'água e monitoramento de nível de reservatório. Foram aplicados conceitos de sistemas embarcados, comunicação sem fio e controle de periféricos via PWM. Os resultados demonstram a eficácia da plataforma RP2040 em aplicações de controle em tempo real e teleoperação robusta.

 \vspace{\onelineskip}
    
 \noindent
 \textbf{Palavras-chave}: Raspberry Pi Pico. NRF24L01. MicroPython. Carro de Bombeiro. Sistemas Embarcados.
\end{resumo}

\begin{resumo}[Abstract]
 \begin{otherlanguage*}{english}
   This report describes the development of a teleoperated fire truck prototype using Raspberry Pi Pico microcontrollers and radio frequency communication (NRF24L01). The system integrates 4WD traction, a water pump fire suppression system, and reservoir level monitoring. Concepts of embedded systems, wireless communication, and peripheral control via PWM were applied. The results demonstrate the effectiveness of the RP2040 platform in real-time control applications and robust teleoperation.

   \vspace{\onelineskip}
 
   \noindent
   \textbf{Keywords}: Raspberry Pi Pico. NRF24L01. MicroPython. Fire Truck. Embedded Systems.
 \end{otherlanguage*}
\end{resumo}

\pdfbookmark[0]{\contentsname}{toc}
\tableofcontents*
\cleardoublepage

% ----------------------------------------------------------
\textual

\chapter{Introdução}

O projeto semestral da disciplina EEN251 --- Projeto Integrador de Sistemas Embarcados propõe o desenvolvimento de um sistema embarcado completo, integrando hardware e software. O tema escolhido foi um carro de bombeiro teleoprado, que combina mobilidade, atuação remota e sensoriamento.

O uso de veículos teleoperados é comum em situações de risco, como o combate a incêndios, onde a segurança humana é prioridade. O protótipo desenvolvido busca simular essas funcionalidades em escala reduzida.

\section{Objetivos}

O objetivo geral deste trabalho é projetar e construir um veículo robótico controlado remotamente via radiofrequência, capaz de realizar manobras de locomoção e acionamento de uma bomba d'água, com monitoramento de status em tempo real.

Como objetivos específicos, destacam-se:
\begin{itemize}
    \item Implementação de comunicação bidirecional robusta entre controle e veículo;
    \item Controle de tração diferencial (tank drive) para quatro motores;
    \item Sistema de alerta de nível de água com indicadores visuais e sonoros;
    \item Desenvolvimento de firmware em MicroPython para a plataforma Raspberry Pi Pico.
\end{itemize}

\chapter{Desenvolvimento do Projeto}

O desenvolvimento foi dividido em três frentes principais: hardware, software e integração de sistemas.

\section{Arquitetura e Diagramas de Blocos}

A Figura \ref{fig:diagrama_geral} apresenta a visão sistêmica do projeto, destacando a separação entre as unidades de controle e de atuação no veículo.

\begin{figure}[htb]
    \centering
    \caption{Diagrama de Blocos do Sistema Completo}
    \label{fig:diagrama_geral}
    \begin{tikzpicture}[node distance=4cm, auto, thick,
        block/.style={rectangle, draw, fill=blue!10, text width=4em, text centered, rounded corners, minimum height=3em},
        cloud/.style={draw, ellipse, fill=red!10, node distance=4cm, minimum height=2em}]
        
        \node [block] (tx) {Controle (TX)};
        \node [cloud, right of=tx] (rf) {RF 2.4GHz};
        \node [block, right of=rf] (rx) {Veículo (RX)};
        
        \path [draw, ->] (tx) -- (rf);
        \path [draw, ->, bend left] (rf) -- node [above, font=\scriptsize] {Comandos} (rx);
        \path [draw, ->, bend left] (rx) -- node [below, font=\scriptsize] {Telemetria} (rf);
        \path [draw, ->] (rf) -- (tx);
    \end{tikzpicture}
    \legend{Fonte: Os autores (2026)}
\end{figure}

\subsection{Subsistema Transmissor (Controle)}

O controle remoto (Figura \ref{fig:diagrama_tx}) processa as entradas do joystick e botões através do Raspberry Pi Pico, transmitindo-as via NRF24L01.

\begin{figure}[htb]
    \centering
    \caption{Fluxo de Dados do Transmissor}
    \label{fig:diagrama_tx}
    \begin{tikzpicture}[node distance=1.5cm, auto, thick,
        cpu/.style={rectangle, draw, fill=gray!20, text width=6em, text centered, minimum height=3.5em},
        inout/.style={rectangle, draw, fill=blue!5, text width=5em, text centered, minimum height=2em}]
        
        \node [cpu] (pico) {RP2040 (Pico TX)};
        \node [inout, above left=0.5cm and 0.5cm of pico] (joy) {Joystick (GP26, 27)};
        \node [inout, left=of pico] (btn) {Botão Bomba (GP19)};
        \node [inout, below left=0.5cm and 0.5cm of pico] (oled) {Display OLED (I2C)};
        \node [inout, right=of pico, fill=orange!20] (nrf) {NRF24L01 (SPI0)};
        
        \draw [->] (joy) -- node [font=\tiny] {ADC} (pico);
        \draw [->] (btn) -- node [font=\tiny] {GPIO} (pico);
        \draw [->] (pico) -- node [font=\tiny] {I2C} (oled);
        \draw [<->] (pico) -- node [font=\tiny] {SPI} (nrf);
    \end{tikzpicture}
    \legend{Fonte: Os autores (2026)}
\end{figure}

\subsection{Subsistema Receptor (Veículo)}

O receptor (Figura \ref{fig:diagrama_rx}) traduz os sinais RF em comandos de potência para os motores e gerencia os sensores de campo.

\begin{figure}[htb]
    \centering
    \caption{Fluxo de Atuação do Receptor}
    \label{fig:diagrama_rx}
    \begin{tikzpicture}[node distance=1.5cm, auto, thick,
        cpu/.style={rectangle, draw, fill=gray!20, text width=6em, text centered, minimum height=3.5em},
        act/.style={rectangle, draw, fill=green!10, text width=5em, text centered, minimum height=2em},
        sens/.style={rectangle, draw, fill=yellow!10, text width=5em, text centered, minimum height=2em}]
        
        \node [cpu] (pico) {RP2040 (Pico RX)};
        \node [act, above left=0.4cm and 0.4cm of pico] (l298n) {2x L298N (Motores)};
        \node [act, left=of pico] (rele) {Relé Bomba (GP8)};
        \node [sens, below left=0.4cm and 0.4cm of pico] (umid) {Sensor Nível (GP27)};
        \node [act, right=of pico, fill=orange!20] (nrf) {NRF24L01 (SPI0)};
        \node [act, below=of pico] (leds) {Indicadores (GP13, 22)};
        
        \draw [->] (pico) -- node [font=\tiny] {PWM} (l298n);
        \draw [->] (pico) -- node [font=\tiny] {GPIO} (rele);
        \draw [->] (umid) -- node [font=\tiny] {ADC} (pico);
        \draw [<->] (pico) -- node [font=\tiny] {SPI} (nrf);
        \draw [->] (pico) -- (leds);
    \end{tikzpicture}
    \legend{Fonte: Os autores (2026)}
\end{figure}

\section{Arquitetura de Hardware}

O sistema é composto por dois nós principais: o Transmissor (Controle) e o Receptor (Veículo). Ambos utilizam o microcontrolador RP2040 \cite{rp2040:datasheet}, presente na placa Raspberry Pi Pico \cite{pico:datasheet}.

\subsection{Transmissor (Controle)}

O controle remoto utiliza um joystick analógico para comandos de direção e botões para acionamento da bomba. Um display OLED SSD1306 foi integrado para fornecer feedback visual ao operador.

\subsection{Receptor (Veículo)}

O veículo possui um chassi 4WD acionado por motores DC. O controle de potência é realizado por drivers L298N \cite{l298n:datasheet}. O sistema possui uma mini bomba submersa acionada por relé.

\section{Comunicação RF (NRF24L01)}

A comunicação utiliza o módulo NRF24L01 \cite{nrf24l01:product} operando em 2.4 GHz. Foi adotado o protocolo Enhanced ShockBurst. Todo o desenvolvimento do rádio foi baseado na biblioteca \cite{nrf24l01:library}.

\section{Software e Firmware}

Todo o código foi desenvolvido em MicroPython \cite{micropython:docs}. O firmware gerencia a recepção de pacotes e o controle de periféricos.

\subsection{Lógica de Movimentação (Tank Drive)}

\begin{lstlisting}[caption={Algoritmo de Tank Drive em MicroPython}]
def drive(x, y):
    motor_esq = max(-100, min(100, y + x))
    motor_dir = max(-100, min(100, y - x))
    set_motor(motor_esq, motor_dir)
\end{lstlisting}

\subsection{Segurança e Failsafe}

\begin{lstlisting}[caption={Logica de Watchdog}]
if time.ticks_diff(time.ticks_ms(), ultimo_sinal) > 500:
    parar()        # Desliga motores por seguranca
\end{lstlisting}

\section{Modelagem 3D e Estrutura Física}

A estrutura física foi projetada em CAD. A Figura \ref{fig:modelagem3d} apresenta a renderização do veículo.

\begin{figure}[htb]
	\caption{\label{fig:modelagem3d}Modelagem 3D do Carro de Bombeiro}
	\begin{center}
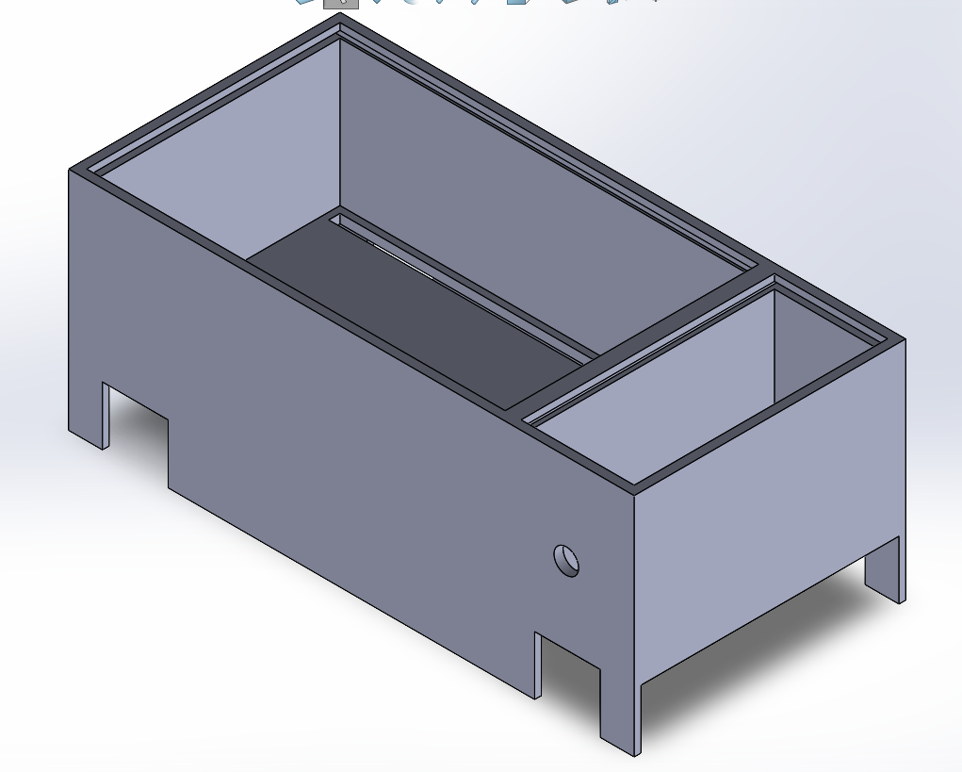
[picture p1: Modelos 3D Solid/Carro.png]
	    
	  \end{center}
	\legend{Fonte: Os autores (2026)}
\end{figure}

\begin{figure}[htb]
    \centering
    \begin{minipage}{0.45\textwidth}
        \centering
        \caption{Base do Controle}
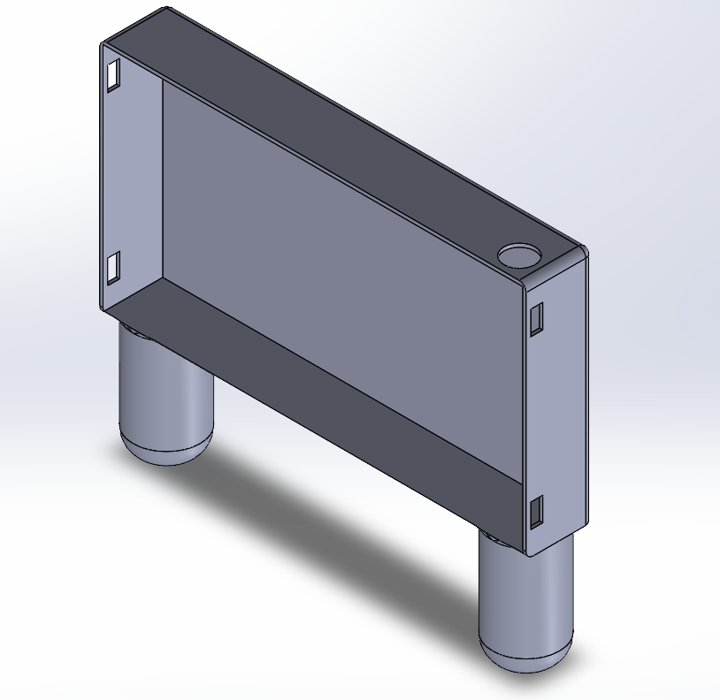
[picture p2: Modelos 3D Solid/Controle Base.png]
        
        \label{fig:controle_base}
    \end{minipage}
    \hfill
    \begin{minipage}{0.45\textwidth}
        \centering
        \caption{Tampa do Controle}
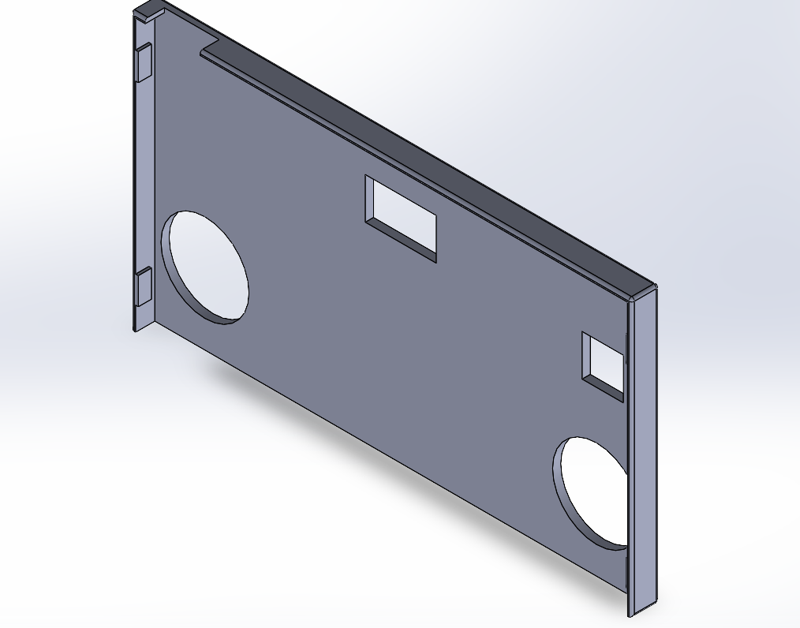
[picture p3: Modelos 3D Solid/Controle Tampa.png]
        
        \label{fig:controle_tampa}
    \end{minipage}
    \legend{Fonte: Os autores (2026)}
\end{figure}

\section{Esquemas Elétricos e PCB}

A Figura \ref{fig:pcb3d} ilustra a visualização 3D da PCB do carro, enquanto a Figura \ref{fig:pcb3d_controle} apresenta a visualização 3D da PCB do controle.

\begin{figure}[htb]
	\caption{\label{fig:pcb3d}Visualização 3D da PCB do Carro}
	\begin{center}
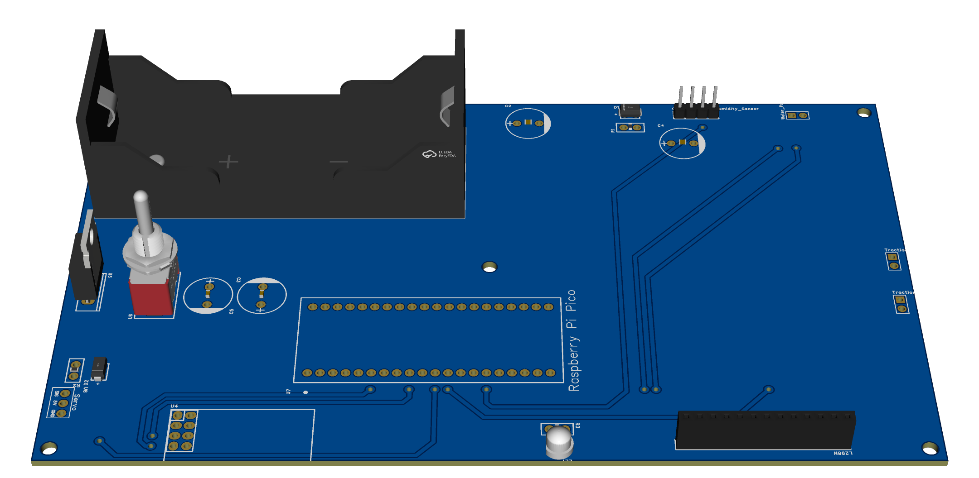
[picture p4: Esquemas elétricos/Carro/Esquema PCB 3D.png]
	    
	  \end{center}
	\legend{Fonte: Os autores (2026)}
\end{figure}

\begin{figure}[htb]
	\caption{\label{fig:pcb3d_controle}Visualização 3D da PCB do Controle}
	\begin{center}
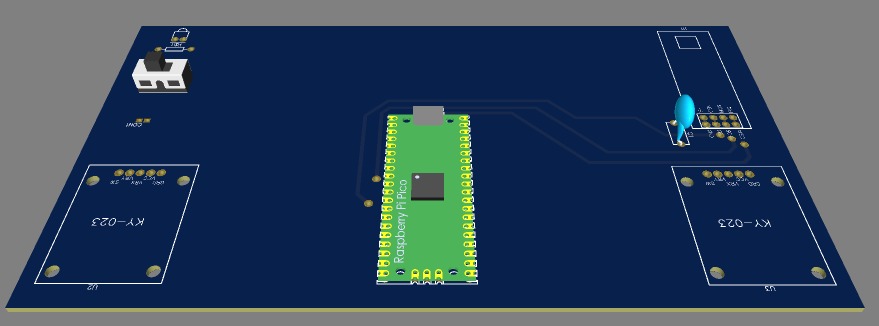
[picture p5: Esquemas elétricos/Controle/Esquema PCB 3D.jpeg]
	    
	  \end{center}
	\legend{Fonte: Os autores (2026)}
\end{figure}

\chapter{Resultados e Discussão}

Neste capítulo são detalhados os resultados práticos da construção do protótipo, analisando a estrutura física, a integração dos componentes eletrônicos e o desempenho do sistema em testes operacionais.

\section{Protótipo do Veículo}

O chassi do veículo, apresentado na Figura \ref{fig:carro_persp}, foi construído através de impressão 3D em material termoplástico, garantindo leveza e resistência estrutural. A mangueira de combate a incêndio foi fixada lateralmente, conectando a bomba submersa interna ao bocal frontal.

\begin{figure}[htb]
    \centering
    \caption{Protótipo Finalizado em Perspectiva}
    \label{fig:carro_persp}
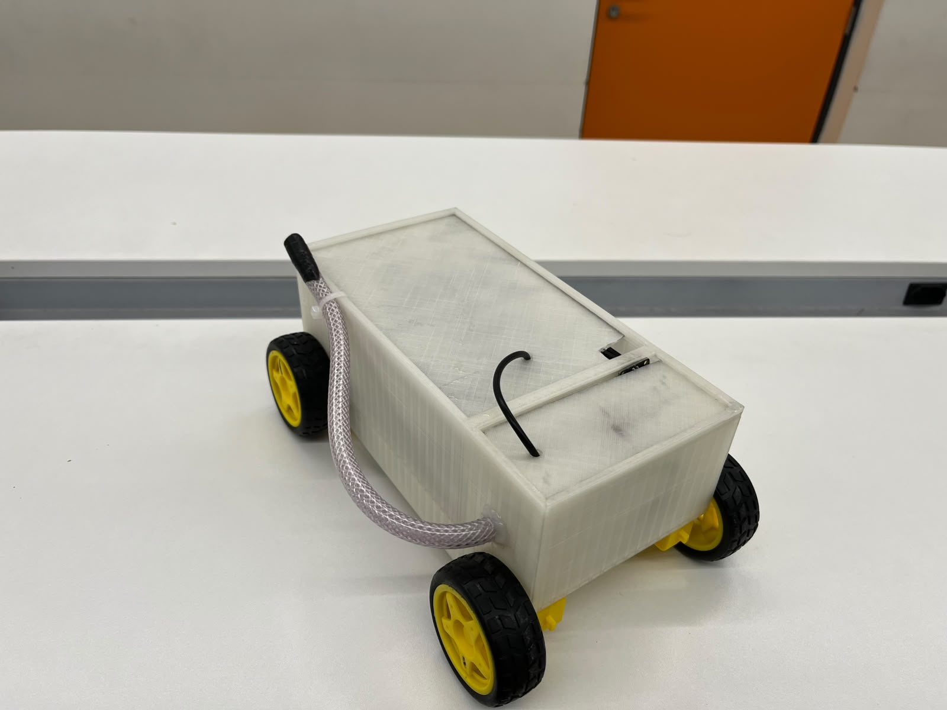
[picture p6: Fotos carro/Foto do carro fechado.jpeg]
    
    \legend{Fonte: Os autores (2026)}
\end{figure}

A vista superior (Figura \ref{fig:carro_vista_superior}) revela a segmentação interna do chassi. O compartimento frontal atua como reservatório de água, enquanto a seção traseira abriga a eletrônica de controle e as fontes de energia, protegidas por tampas removíveis que facilitam a manutenção e o reabastecimento.

\begin{figure}[htb]
    \centering
    \caption{Vista Superior Detalhando a Segmentação do Chassi}
    \label{fig:carro_vista_superior}
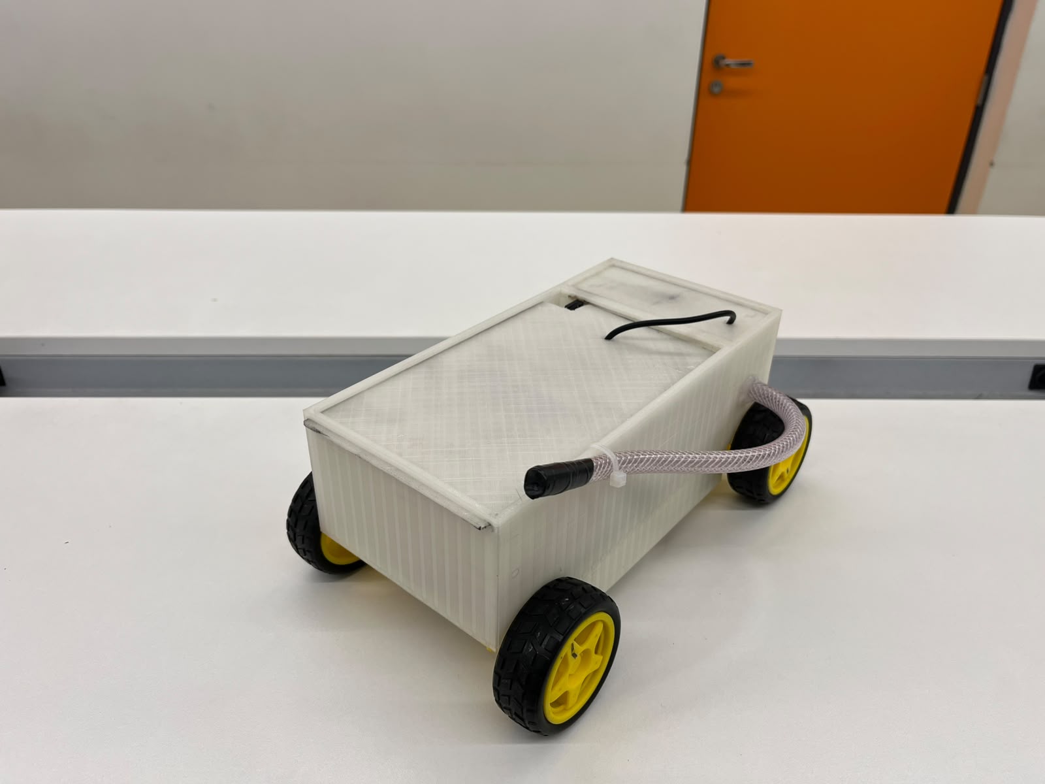
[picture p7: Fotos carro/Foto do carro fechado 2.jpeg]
    
    \legend{Fonte: Os autores (2026)}
\end{figure}

\section{Unidade de Controle Remoto}

A unidade de controle foi projetada com foco na ergonomia e funcionalidade. Internamente (Figura \ref{fig:interna_controle}), destaca-se a PCB de face simples confeccionada artesanalmente, que centraliza as conexões dos joysticks analógicos, do módulo NRF24L01 com antena externa e da bateria de lítio recarregável.

\begin{figure}[htb]
    \centering
    \caption{Montagem Interna da Unidade de Controle}
    \label{fig:interna_controle}
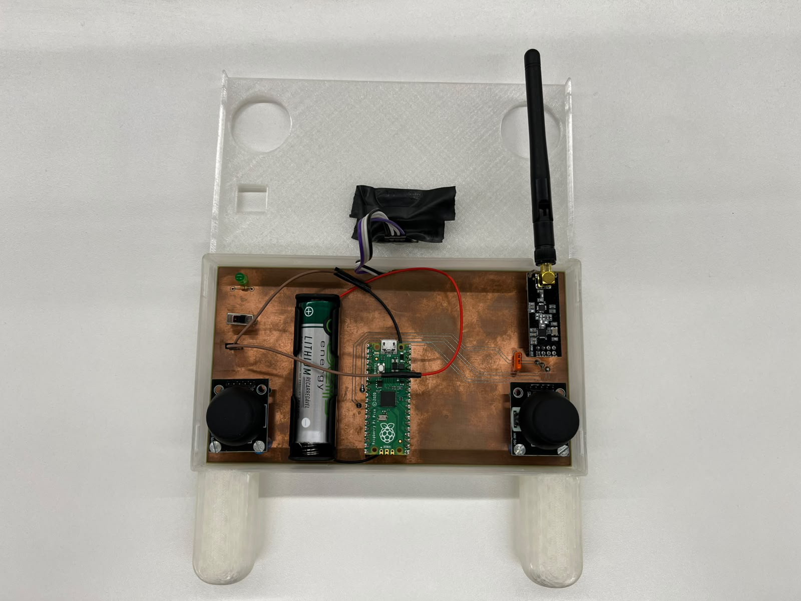
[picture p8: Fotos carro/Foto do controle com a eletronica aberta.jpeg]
    
    \legend{Fonte: Os autores (2026)}
\end{figure}

Externamente (Figura \ref{fig:controle_final}), o controle apresenta um layout intuitivo. O display OLED centralizado fornece informações em tempo real sobre o status da conexão e o nível do reservatório, enquanto o interruptor tipo alavanca gerencia a alimentação do sistema.

\begin{figure}[htb]
    \centering
    \caption{Unidade de Controle Finalizada (Vista Externa)}
    \label{fig:controle_final}
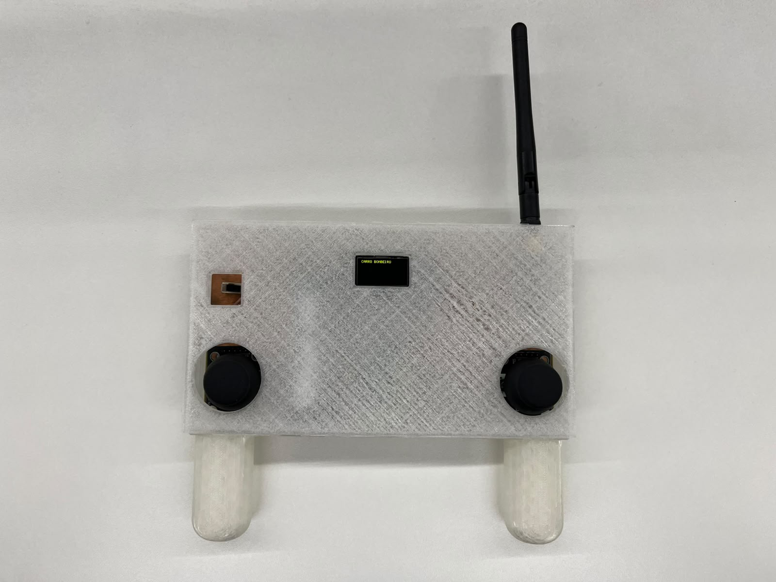
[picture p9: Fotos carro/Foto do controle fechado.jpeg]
    
    \legend{Fonte: Os autores (2026)}
\end{figure}

\section{Integração Eletrônica e Sistema de Tração}

A Figura \ref{fig:interna_carro} ilustra o arranjo dos componentes eletrônicos no veículo. O Raspberry Pi Pico coordena as operações, recebendo comandos via RF e controlando o driver de potência L298N para a movimentação dos motores.

\begin{figure}[htb]
    \centering
    \caption{Arranjo da Eletrônica de Controle no Veículo}
    \label{fig:interna_carro}
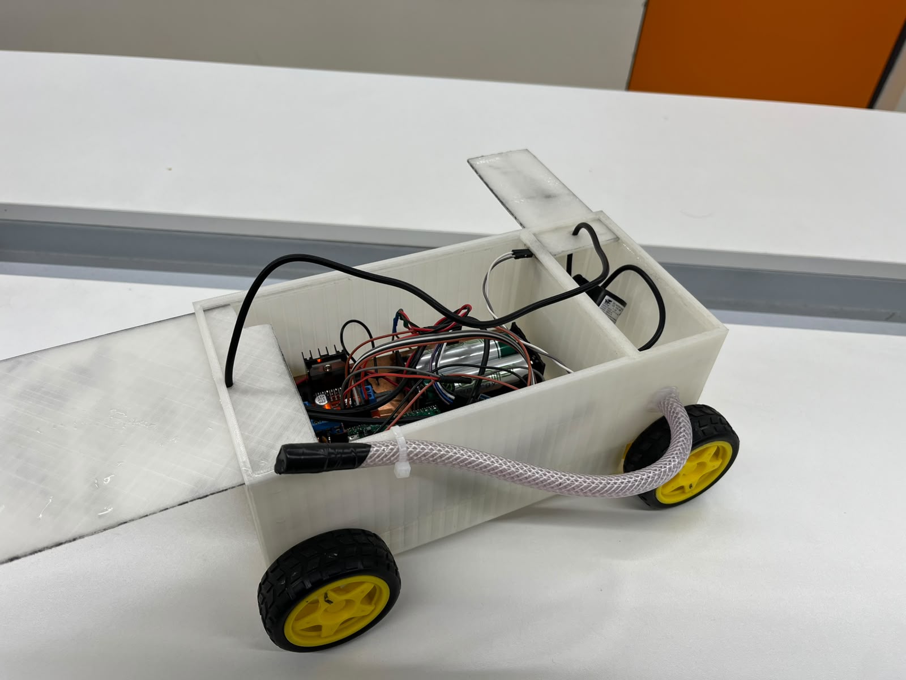
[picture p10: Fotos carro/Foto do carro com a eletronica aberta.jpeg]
    
    \legend{Fonte: Os autores (2026)}
\end{figure}

O sistema de tração 4WD (Figura \ref{fig:vista_inferior}) utiliza quatro motores DC com redução, permitindo que o veículo supere pequenos obstáculos e execute manobras diferenciais. A fiação foi organizada para evitar interferências mecânicas com os eixos das rodas.

\begin{figure}[htb]
    \centering
    \caption{Sistema de Tração 4WD e Motores DC}
    \label{fig:vista_inferior}
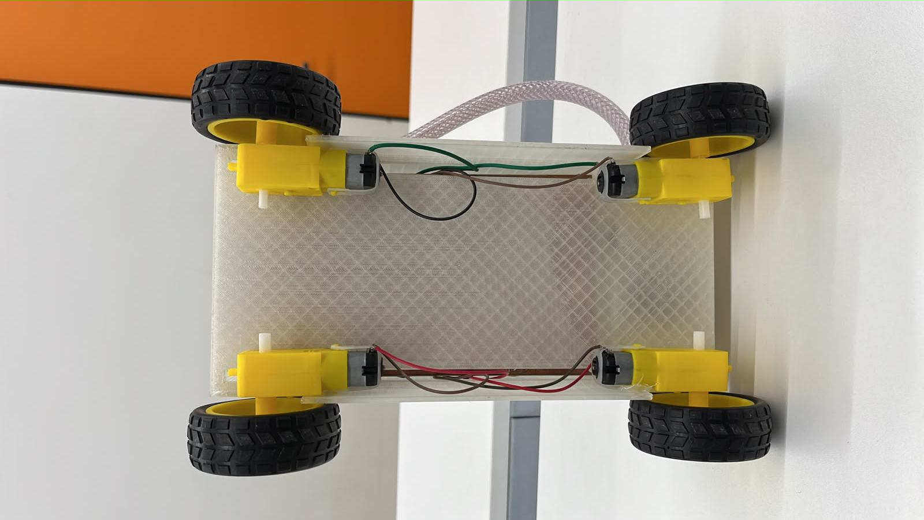
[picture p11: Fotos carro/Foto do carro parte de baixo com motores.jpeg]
    
    \legend{Fonte: Os autores (2026)}
\end{figure}

\section{Análise de Desempenho}

Os testes de campo validaram a eficiência da comunicação bidirecional. A latência percebida foi mínima, permitindo uma resposta imediata aos comandos de direção. O sistema de segurança \textit{failsafe} atuou corretamente durante simulações de perda de sinal, interrompendo imediatamente a propulsão do veículo.

\chapter{Conclusão}

O projeto do carro de bombeiro teleoprado foi concluído com sucesso, atingindo todos os requisitos funcionais estabelecidos inicialmente. A integração entre o microcontrolador Raspberry Pi Pico e o módulo NRF24L01 mostrou-se uma solução robusta para comunicação sem fio de baixa latência, permitindo um controle preciso mesmo em ambientes com interferência.

A implementação do algoritmo de controle \textit{tank drive} possibilitou uma movimentação ágil e manobrável, essencial para o propósito de um veículo de intervenção. O sistema de combate a incêndio, composto pela bomba d'água e monitoramento de nível, funcionou conforme o esperado, agregando valor técnico ao protótipo através da integração de diferentes tipos de atuadores e sensores.

O desenvolvimento deste trabalho permitiu a consolidação de conhecimentos fundamentais em sistemas embarcados, incluindo programação em MicroPython, protocolos de comunicação (SPI e I2C), controle de potência com PWM e design de hardware. A experiência de projetar, montar e validar um sistema completo preparou a equipe para desafios mais complexos na área de robótica e eletrônica.

Como sugestões para trabalhos futuros, destaca-se a implementação de um sistema de controle de bocal automatizado via servomotores e a integração de sensores de chama para permitir modos de operação autônomos.

\postextual

% ----------------------------------------------------------
% Referências bibliográficas
% ----------------------------------------------------------
\bibliography{referencias}

% ---
% Apêndices
% ---
\begin{apendicesenv}
\partapendices

\chapter{Código Fonte do Receptor}
\lstinputlisting[language=Python]{../../src/carro de bombeiro/carro.py}

\chapter{Código Fonte do Transmissor}
\lstinputlisting[language=Python]{../../src/controle/controle.py}

\chapter{Modificação Técnica da Bomba d'Água}
A Figura \ref{fig:mod_bomba} detalha a alteração realizada no circuito de acionamento da bomba d'água para permitir o controle via transistor, garantindo o acionamento adequado a partir do sinal de controle do microcontrolador.

\begin{figure}[htb]
    \centering
    \caption{Esquema da Modificação da Bomba d'Água}
    \label{fig:mod_bomba}
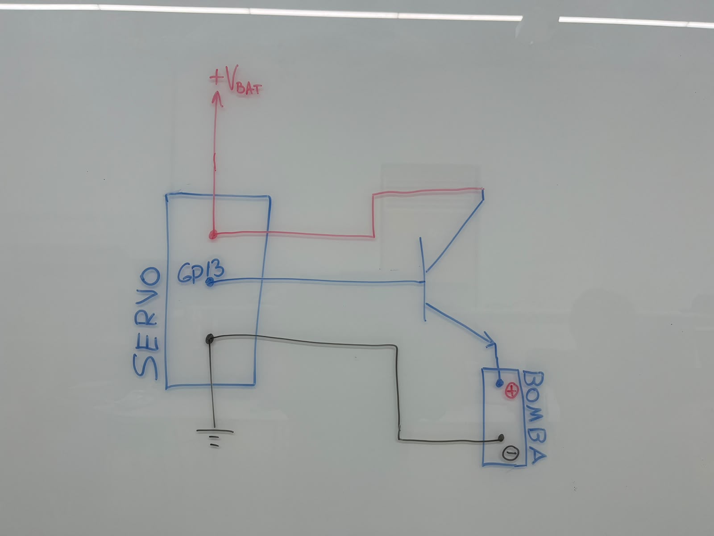
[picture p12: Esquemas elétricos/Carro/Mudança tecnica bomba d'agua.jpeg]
    
    \legend{Fonte: Os autores (2026)}
\end{figure}

\end{apendicesenv}

% ---
% Anexos
% ---
\begin{anexosenv}
\partanexos

\chapter{Esquema Elétrico do Carro}
\includepdf[pages=-]{../../Esquemas elétricos/Carro/Esquema elétrico.pdf}

\chapter{Layout da PCB do Carro}
\includepdf[pages=-]{../../Esquemas elétricos/Carro/Esquema PCB.pdf}

\chapter{Esquema Elétrico do Controle}
\includepdf[pages=-]{../../Esquemas elétricos/Controle/controle_bombeiro.pdf}

\chapter{Layout da PCB do Controle}
\includepdf[pages=-]{../../Esquemas elétricos/Controle/Esquema PCB.pdf}

\end{anexosenv}

\end{document}

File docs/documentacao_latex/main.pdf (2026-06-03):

## Felipe Fazio da Costa, RA: 23.00055-4

## João Gabriel Fioruci Roberto, RA: 23.00617-0

## Gabriel Rodrigues Marques, RA: 23.00578-5

## Fábio Sadao Sato, RA: 22.00984-0

# Projeto Semestral: Carro de Bombeiro

# Teleoprado

## Brasil

2026

## Felipe Fazio da Costa, RA: 23.00055-4

## João Gabriel Fioruci Roberto, RA: 23.00617-0

## Gabriel Rodrigues Marques, RA: 23.00578-5 Fábio Sadao Sato, RA: 22.00984-0

# Projeto Semestral: Carro de Bombeiro Teleoprado

## Relatório técnico apresentado como requisito parcial para aprovação na disciplina EEN251 — Projeto Integrador de Sistemas Embarcados

do curso de Engenharia.

## Centro Universitário Instituto Mauá de Tecnologia

## Engenharia de Computação / Eletrônica

## Disciplina: EEN251 — Projeto de Sistemas Embarcados

## Brasil

2026

# Resumo

## Este relatório descreve o desenvolvimento de um protótipo de carro de bombeiro teleoprado

## utilizando microcontroladores Raspberry Pi Pico e comunicação via rádio frequência (NRF24L01). O sistema integra tração 4WD, sistema de combate a incêndio por bomba

## d’água e monitoramento de nível de reservatório. Foram aplicados conceitos de sistemas

## embarcados, comunicação sem fio e controle de periféricos via PWM. Os resultados

## demonstram a eficácia da plataforma RP2040 em aplicações de controle em tempo real e

teleoperação robusta.

Palavras-chave: Raspberry Pi Pico. NRF24L01. MicroPython. Carro de Bombeiro. Sistemas Embarcados.

# Abstract

This report describes the development of a teleoperated fire truck prototype using Raspberry

## Pi Pico microcontrollers and radio frequency communication (NRF24L01). The system

## integrates 4WD traction, a water pump fire suppression system, and reservoir level

## monitoring. Concepts of embedded systems, wireless communication, and peripheral

## control via PWM were applied. The results demonstrate the effectiveness of the RP2040

platform in real-time control applications and robust teleoperation.

Keywords: Raspberry Pi Pico. NRF24L01. MicroPython. Fire Truck. Embedded Systems.

# Sumário

APÊNDICES | 20

## APÊNDICE C – MODIFICAÇÃO TÉCNICA DA BOMBA D’ÁGUA 35

ANEXOS | 36

6

# 1 Introdução

## O projeto semestral da disciplina EEN251 — Projeto Integrador de Sistemas

## Embarcados propõe o desenvolvimento de um sistema embarcado completo, integrando

## hardware e software. O tema escolhido foi um carro de bombeiro teleoprado, que combina

mobilidade, atuação remota e sensoriamento.

## O uso de veículos teleoperados é comum em situações de risco, como o combate a

## incêndios, onde a segurança humana é prioridade. O protótipo desenvolvido busca simular

essas funcionalidades em escala reduzida.

# 1.1 Objetivos

## O objetivo geral deste trabalho é projetar e construir um veículo robótico controlado

## remotamente via radiofrequência, capaz de realizar manobras de locomoção e acionamento

de uma bomba d’água, com monitoramento de status em tempo real.

## Como objetivos específicos, destacam-se:

- Implementação de comunicação bidirecional robusta entre controle e veículo;
- Controle de tração diferencial (tank drive) para quatro motores;
- Sistema de alerta de nível de água com indicadores visuais e sonoros;
- Desenvolvimento de firmware em MicroPython para a plataforma Raspberry Pi Pico.

7

# 2 Desenvolvimento do Projeto

## O desenvolvimento foi dividido em três frentes principais: hardware, software e

integração de sistemas.

# 2.1 Arquitetura e Diagramas de Blocos

## A Figura 1 apresenta a visão sistêmica do projeto, destacando a separação entre as

unidades de controle e de atuação no veículo.

## Figura 1 – Diagrama de Blocos do Sistema Completo

## Controle

(TX) | RF 2.4GHz

## Veículo

(RX)

Comandos

Telemetria

## Fonte: Os autores (2026)

## 2.1.1 Subsistema Transmissor (Controle)

## O controle remoto (Figura 2) processa as entradas do joystick e botões através do

Raspberry Pi Pico, transmitindo-as via NRF24L01.

## Figura 2 – Fluxo de Dados do Transmissor

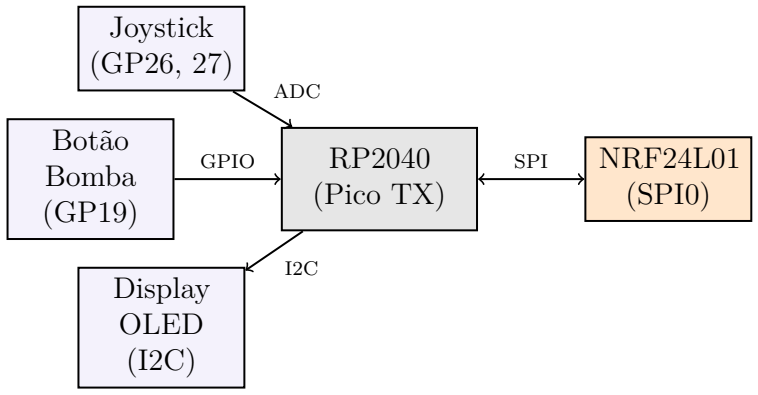
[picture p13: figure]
RP2040 (Pico TX); Joystick (GP26, 27); Botão Bomba (GP19); Display OLED (I2C); NRF24L01 (SPI0); ADC; GPIO; SPI

## Fonte: Os autores (2026)

## 2.1.2 Subsistema Receptor (Veículo)

## O receptor (Figura 3) traduz os sinais RF em comandos de potência para os motores

e gerencia os sensores de campo.

Capítulo 2. Desenvolvimento do Projeto | 8

## Figura 3 – Fluxo de Atuação do Receptor

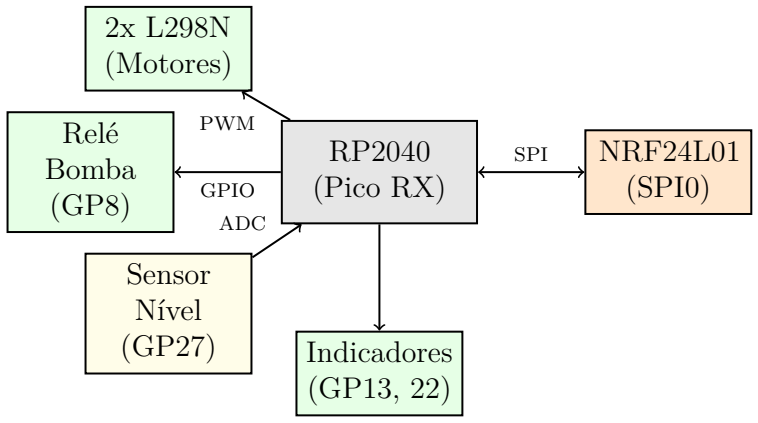
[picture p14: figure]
RP2040 (Pico RX); 2x L298N (Motores); Relé Bomba (GP8); Sensor Nível (GP27); NRF24L01 (SPI0); Indicadores (GP13, 22); PWM; GPIO; ADC; SPI

## Fonte: Os autores (2026)

# 2.2 Arquitetura de Hardware

## O sistema é composto por dois nós principais: o Transmissor (Controle) e o Receptor

(Veículo). Ambos utilizam o microcontrolador RP2040 (RASPBERRY PI LTD, 2026b), presente na placa Raspberry Pi Pico (RASPBERRY PI LTD, 2026a).

## 2.2.1 Transmissor (Controle)

## O controle remoto utiliza um joystick analógico para comandos de direção e botões

## para acionamento da bomba. Um display OLED SSD1306 foi integrado para fornecer

feedback visual ao operador.

## 2.2.2 Receptor (Veículo)

## O veículo possui um chassi 4WD acionado por motores DC. O controle de potência é realizado por drivers L298N (STMICROELECTRONICS, 2026). O sistema possui uma

mini bomba submersa acionada por relé.

# 2.3 Comunicação RF (NRF24L01)

## A comunicação utiliza o módulo NRF24L01 (NORDIC SEMICONDUCTOR, 2026)

## operando em 2.4 GHz. Foi adotado o protocolo Enhanced ShockBurst. Todo o desenvolvi-

mento do rádio foi baseado na biblioteca (MICROPYTHON-NRF24L01. . . , 2026).

Capítulo 2. Desenvolvimento do Projeto | 9

# 2.4 Software e Firmware

Todo o código foi desenvolvido em MicroPython (MICROPYTHON PROJECT, 2026). O firmware gerencia a recepção de pacotes e o controle de periféricos.

## 2.4.1 Lógica de Movimentação (Tank Drive)

1 | def drive (x , y ) :
2 | motor_esq = max ( -100 , min (100 , y + x ) )
3 | motor_dir = max ( -100 , min (100 , y - x ) )
4 | set_motor ( motor_esq , motor_dir )

## Listing 2.1 – Algoritmo de Tank Drive em MicroPython

## 2.4.2 Segurança e Failsafe

1 | if time . ticks_diff ( time . ticks_ms () , ultimo_sinal ) > 500:
2 | parar () | # Desliga motores por seguranca

## Listing 2.2 – Logica de Watchdog

# 2.5 Modelagem 3D e Estrutura Física

## A estrutura física foi projetada em CAD. A Figura 4 apresenta a renderização do

veículo.

# 2.6 Esquemas Elétricos e PCB

## A Figura 7 ilustra a visualização 3D da PCB do carro, enquanto a Figura 8

apresenta a visualização 3D da PCB do controle.

## Figura 4 – Modelagem 3D do Carro de Bombeiro

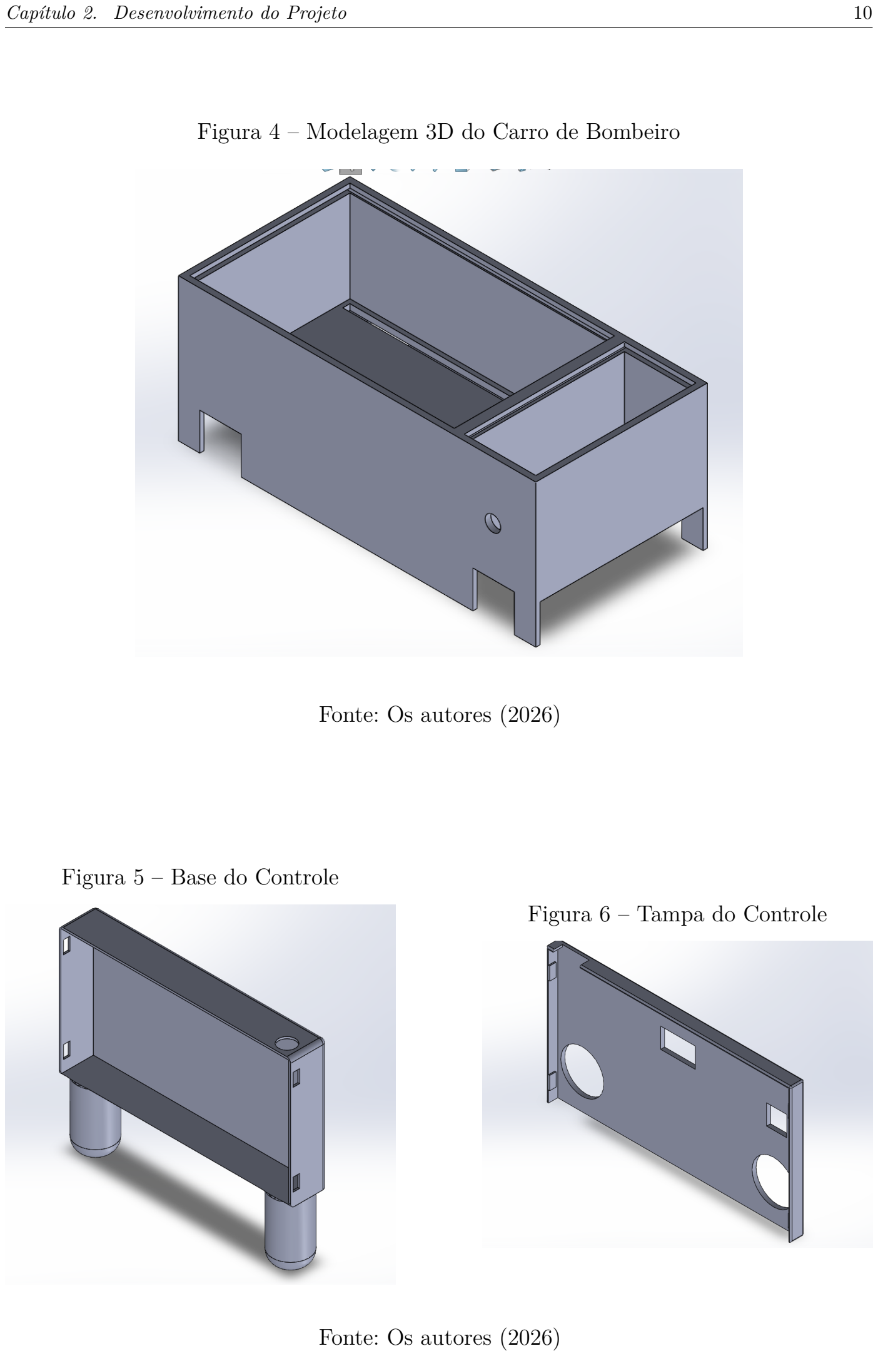
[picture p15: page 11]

Capítulo 2. Desenvolvimento do Projeto | 10

## Fonte: Os autores (2026)

## Figura 5 – Base do Controle

## Figura 6 – Tampa do Controle

## Fonte: Os autores (2026)

Capítulo 2. Desenvolvimento do Projeto | 11

## Figura 7 – Visualização 3D da PCB do Carro

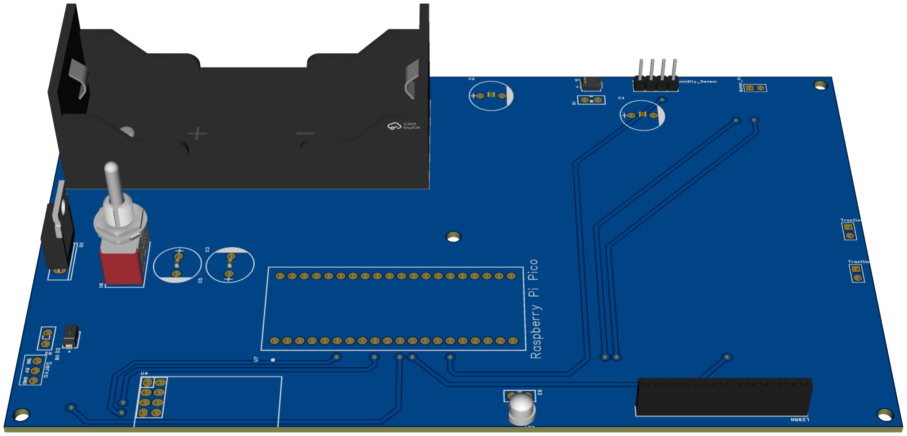
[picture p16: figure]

## Fonte: Os autores (2026)

## Figura 8 – Visualização 3D da PCB do Controle

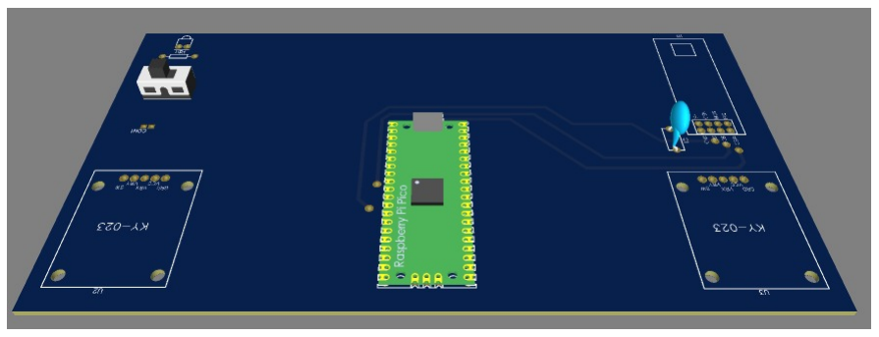
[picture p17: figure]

## Fonte: Os autores (2026)

12

# 3 Resultados e Discussão

Neste capítulo são detalhados os resultados práticos da construção do protótipo,

## analisando a estrutura física, a integração dos componentes eletrônicos e o desempenho do

sistema em testes operacionais.

# 3.1 Protótipo do Veículo

## O chassi do veículo, apresentado na Figura 9, foi construído através de impressão

## 3D em material termoplástico, garantindo leveza e resistência estrutural. A mangueira

## de combate a incêndio foi fixada lateralmente, conectando a bomba submersa interna ao

bocal frontal.

## Figura 9 – Protótipo Finalizado em Perspectiva


## Fonte: Os autores (2026)

## A vista superior (Figura 10) revela a segmentação interna do chassi. O comparti-

mento frontal atua como reservatório de água, enquanto a seção traseira abriga a eletrônica

## de controle e as fontes de energia, protegidas por tampas removíveis que facilitam a

manutenção e o reabastecimento.

Capítulo 3. Resultados e Discussão | 13

## Figura 10 – Vista Superior Detalhando a Segmentação do Chassi


## Fonte: Os autores (2026)

# 3.2 Unidade de Controle Remoto

A unidade de controle foi projetada com foco na ergonomia e funcionalidade. Internamente (Figura 11), destaca-se a PCB de face simples confeccionada artesanalmente,

## que centraliza as conexões dos joysticks analógicos, do módulo NRF24L01 com antena

externa e da bateria de lítio recarregável.

## Externamente (Figura 12), o controle apresenta um layout intuitivo. O display

## OLED centralizado fornece informações em tempo real sobre o status da conexão e o nível

do reservatório, enquanto o interruptor tipo alavanca gerencia a alimentação do sistema.

# 3.3 Integração Eletrônica e Sistema de Tração

## A Figura 13 ilustra o arranjo dos componentes eletrônicos no veículo. O Raspberry

## Pi Pico coordena as operações, recebendo comandos via RF e controlando o driver de

potência L298N para a movimentação dos motores.

O sistema de tração 4WD (Figura 14) utiliza quatro motores DC com redução,

## permitindo que o veículo supere pequenos obstáculos e execute manobras diferenciais. A

fiação foi organizada para evitar interferências mecânicas com os eixos das rodas.

Capítulo 3. Resultados e Discussão | 14

## Figura 11 – Montagem Interna da Unidade de Controle

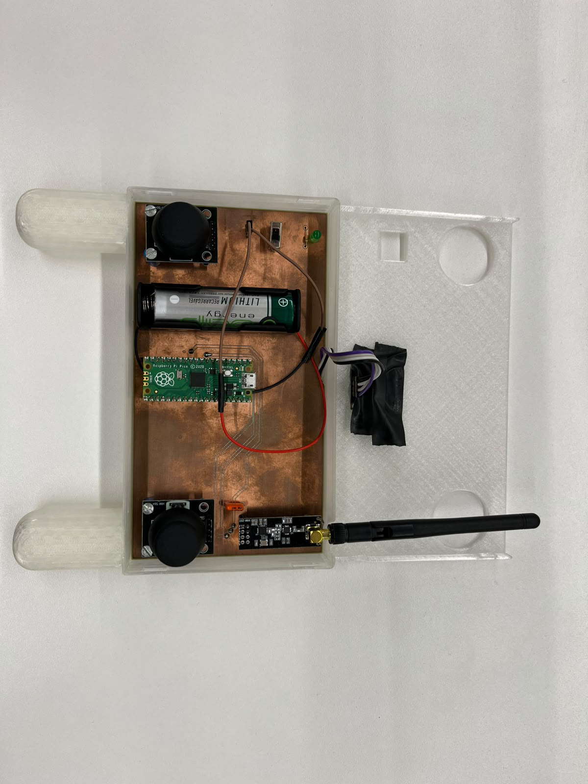
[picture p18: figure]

## Fonte: Os autores (2026)

# 3.4 Análise de Desempenho

## Os testes de campo validaram a eficiência da comunicação bidirecional. A latência

## percebida foi mínima, permitindo uma resposta imediata aos comandos de direção. O

sistema de segurança failsafe atuou corretamente durante simulações de perda de sinal, interrompendo imediatamente a propulsão do veículo.

Capítulo 3. Resultados e Discussão | 15

## Figura 12 – Unidade de Controle Finalizada (Vista Externa)

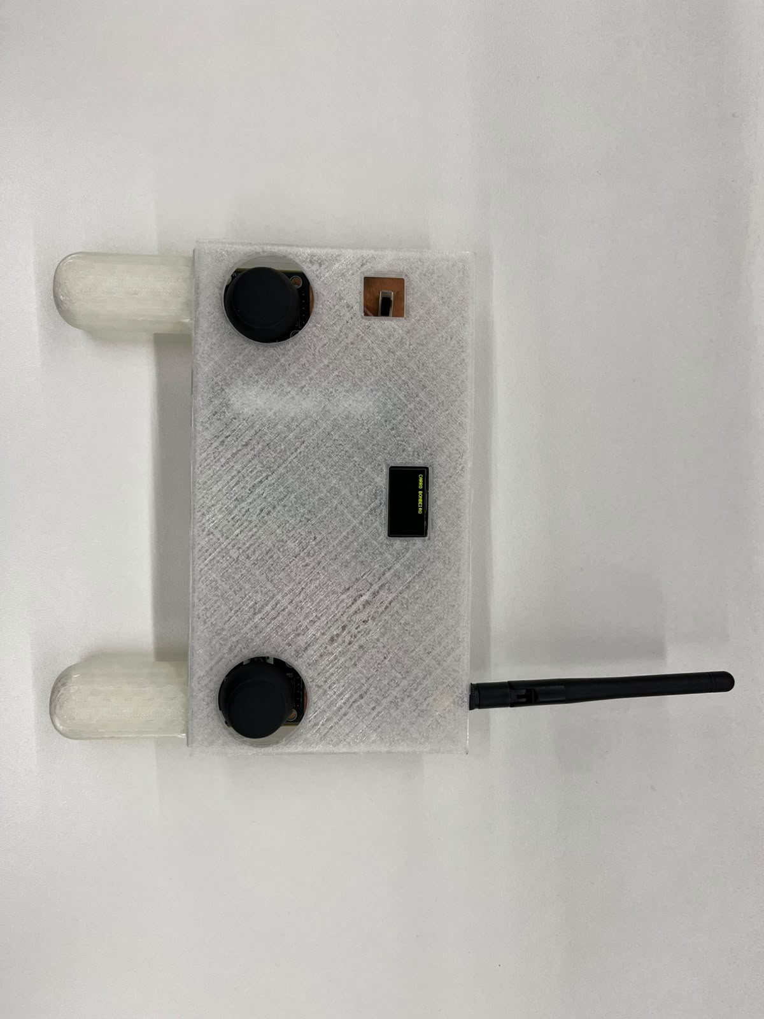
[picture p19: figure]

## Fonte: Os autores (2026)

Capítulo 3. Resultados e Discussão | 16

## Figura 13 – Arranjo da Eletrônica de Controle no Veículo


## Fonte: Os autores (2026)

Capítulo 3. Resultados e Discussão | 17

## Figura 14 – Sistema de Tração 4WD e Motores DC

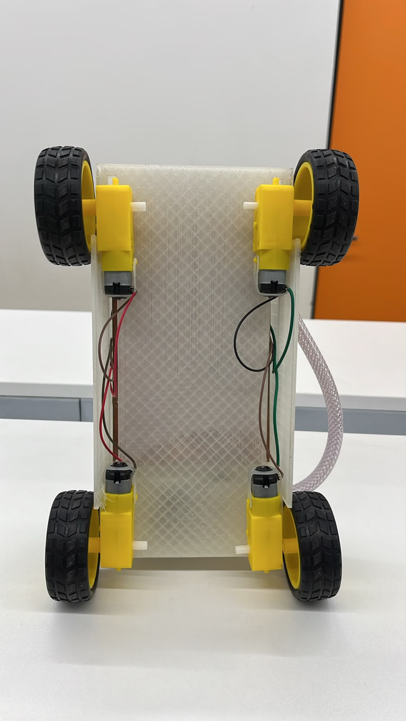
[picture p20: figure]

## Fonte: Os autores (2026)

18

# 4 Conclusão

## O projeto do carro de bombeiro teleoprado foi concluído com sucesso, atingindo

## todos os requisitos funcionais estabelecidos inicialmente. A integração entre o micro-

## controlador Raspberry Pi Pico e o módulo NRF24L01 mostrou-se uma solução robusta

## para comunicação sem fio de baixa latência, permitindo um controle preciso mesmo em

ambientes com interferência.

## A implementação do algoritmo de controle tank drive possibilitou uma movimen-

## tação ágil e manobrável, essencial para o propósito de um veículo de intervenção. O

sistema de combate a incêndio, composto pela bomba d’água e monitoramento de nível,

## funcionou conforme o esperado, agregando valor técnico ao protótipo através da integração

de diferentes tipos de atuadores e sensores.

## O desenvolvimento deste trabalho permitiu a consolidação de conhecimentos fun-

## damentais em sistemas embarcados, incluindo programação em MicroPython, protocolos de comunicação (SPI e I2C), controle de potência com PWM e design de hardware. A

## experiência de projetar, montar e validar um sistema completo preparou a equipe para

desafios mais complexos na área de robótica e eletrônica.

## Como sugestões para trabalhos futuros, destaca-se a implementação de um sistema

## de controle de bocal automatizado via servomotores e a integração de sensores de chama

para permitir modos de operação autônomos.

19

# Referências Bibliográficas

## MICROPYTHON-NRF24L01 Library. 2026. Acesso em: mar. 2026. Disponível em: <https://github.com/micropython/micropython-lib/tree/master/micropython/drivers/

radio/nrf24l01>. (https://github.com/micropython/micropython-lib/tree/master/micropython/drivers/radio/nrf24l01) Citado na página 8.

## MICROPYTHON PROJECT. MicroPython Documentation for RP2. 2026. Acesso

em: mar. 2026. Disponível em: <https://docs.micropython.org/en/latest/rp2/quickref. html>. (https://docs.micropython.org/en/latest/rp2/quickref.html) Citado na página 9.

NORDIC SEMICONDUCTOR. nRF24L01+ Product Specification v1.0. [S.l.], 2026. Acesso em: mar. 2026. Disponível em: <https://www.nordicsemi.com/products/nrf24l01>. Citado na página 8.

RASPBERRY PI LTD. Raspberry Pi Pico Datasheet. [S.l.], 2026. Acesso em: mar. 2026. Disponível em: <https://datasheets.raspberrypi.com/pico/pico-datasheet.pdf>. Citado na página 8.

RASPBERRY PI LTD. RP2040 Datasheet. [S.l.], 2026. Acesso em: mar. 2026. Disponível em: <https://datasheets.raspberrypi.com/rp2040/rp2040-datasheet.pdf>. Citado na página 8.

STMICROELECTRONICS. L298N Dual Full-Bridge Driver Datasheet. [S.l.], 2026. Acesso em: mar. 2026. Disponível em: <https://www.st.com/resource/en/datasheet/l298. pdf>. (https://www.st.com/resource/en/datasheet/l298.pdf) Citado na página 8.

# Apêndices

21

# APÊNDICE A – Código Fonte do Receptor

1 | from machine import Pin , SPI , PWM , ADC
2 | import time

3

4 | # ========================
5 | # SPI NRF24L01
6 | # ========================
7 | spi = SPI (0 ,
8 | | baudrate =1000000 ,
9 | | polarity =0 ,
10 | | phase =0 ,
11 | | sck = Pin (6) ,
12 | | mosi = Pin (7) ,
13 | | miso = Pin (4) )
14 | csn = Pin (5 , Pin . OUT )
15 | ce | = Pin (12 , Pin . OUT )

16

17 | # ========================
18 | # L298N - PONTE H
19 | # ========================
20 | in1 = Pin (0 , Pin . OUT )
21 | in2 = Pin (1 , Pin . OUT )
22 | ena = PWM ( Pin (9) )
23 | ena . freq (1000)

24
25 | in3 = Pin (2 , Pin . OUT )
26 | in4 = Pin (3 , Pin . OUT )
27 | enb = PWM ( Pin (10) )
28 | enb . freq (1000)

29
30 | in1 . value (0)
31 | in2 . value (0)
32 | in3 . value (0)
33 | in4 . value (0)
34 | ena . duty_u16 (0)
35 | enb . duty_u16 (0)

36

37 | # ========================
38 | # BOMBA D’Á GUA - GP8
39 | # ========================
40 | bomba = Pin (8 , Pin . OUT )
41 | bomba . value (0)

42

43 # LED indicador

APÊNDICE A. Código Fonte do Receptor | 22
44 | led = Pin (13 , Pin . OUT )

45

46 | # ========================
47 | # SENSOR DE UMIDADE
48 | # ========================
49 | umidade_analog | = ADC ( Pin (27) )
50 | umidade_digital = Pin (22 , Pin . IN )

51
52 | FORA | = 60000
53 | SUBMERSO = 10000

54
55 | def ler_umidade () :
56 | raw = sum ( umidade_analog . read_u16 () for _ in range (10) ) // 10
57 | nivel = ( FORA - raw ) * 100 // ( FORA - SUBMERSO )
58 | nivel = max (0 , min (100 , nivel ) )
59 | digital = 1 if umidade_digital . value () == 0 else 0
60 | return nivel , digital

61

62 | # ========================
63 | # ENDERE ÇOS
64 | # ========================
65 | ADDR_CONTROLE = [0 xE7 ,0 xE7 ,0 xE7 ,0 xE7 ,0 xE7 ]
66 | ADDR_CARRO | = [0 xC2 ,0 xC2 ,0 xC2 ,0 xC2 ,0 xC2 ]

67

68 | # ========================
69 | # DRIVER NRF24L01
70 | # ========================
71 | class NRF24 :
72 | def __init__ ( self , spi , csn , ce ) :
73 | self . spi = spi
74 | self . csn = csn
75 | self . ce | = ce
76 | self . csn . value (1)
77 | self . ce . value (0)
78 | self . init_rx ()

79
80 | def write_reg ( self , reg , value ) :
81 | self . csn . value (0)
82 | self . spi . write ( bytearray ([0 x20 | reg , value ]) )
83 | self . csn . value (1)

84
85 | def read_reg ( self , reg ) :
86 | self . csn . value (0)
87 | self . spi . write ( bytearray ([ reg & 0 x1F ]) )
88 | result = self . spi . read (1)
89 | self . csn . value (1)
90 | return result [0]

APÊNDICE A. Código Fonte do Receptor | 23

91
92 | def set_addr ( self , pipe_reg , addr_bytes ) :
93 | self . csn . value (0)
94 | self . spi . write ( bytearray ([0 x20 | pipe_reg ]) + bytearray (

addr_bytes ) )

95 | self . csn . value (1)

96
97 | def flush_rx ( self ) :
98 | self . csn . value (0)
99 | self . spi . write ( bytearray ([0 xE2 ]) )
100 | self . csn . value (1)

101
102 | def flush_tx ( self ) :
103 | self . csn . value (0)
104 | self . spi . write ( bytearray ([0 xE1 ]) )
105 | self . csn . value (1)

106
107 | def init_rx ( self ) :
108 | time . sleep_ms (100)
109 | self . write_reg (0 x00 , 0 x0B ) | # Power up + RX
110 | self . write_reg (0 x01 , 0 x00 ) | # Sem auto -ack
111 | self . write_reg (0 x02 , 0 x01 ) | # Pipe 0 habilitado
112 | self . write_reg (0 x05 , 0 x02 ) | # Canal 2
113 | self . write_reg (0 x06 , 0 x26 ) | # Data rate 1 Mbps

114
115 | self . set_addr (0 x0A , ADDR_CARRO ) | # RX pipe 0 addr
116 | self . set_addr (0 x10 , ADDR_CONTROLE ) | # TX addr ( resposta )
117 | self . write_reg (0 x11 , 4) | # Payload pipe 0 = 4 bytes

118
119 | self . flush_rx ()
120 | self . flush_tx ()
121 | self . write_reg (0 x07 , 0 x70 )
122 | self . ce . value (1)

123
124 | def modo_tx ( self ) :
125 | self . ce . value (0)
126 | self . write_reg (0 x00 , 0 x0A )
127 | self . set_addr (0 x10 , ADDR_CONTROLE ) | # TX aponta para o controle
128 | self . flush_tx ()
129 | time . sleep_us (150)

130
131 | def modo_rx ( self ) :
132 | self . ce . value (0)
133 | self . write_reg (0 x00 , 0 x0B )
134 | self . set_addr (0 x0A , ADDR_CARRO )
135 | self . flush_rx ()
136 | self . write_reg (0 x07 , 0 x70 )

APÊNDICE A. Código Fonte do Receptor | 24
137 | self . ce . value (1)
138 | time . sleep_us (150)

139
140 | def available ( self ) :
141 | status = self . read_reg (0 x07 )
142 | if status & 0 x10 :
143 | self . write_reg (0 x07 , 0 x70 )
144 | self . flush_rx ()
145 | return ( status & 0 x40 ) != 0

146
147 | def receive ( self ) :
148 | self . csn . value (0)
149 | self . spi . write ( bytearray ([0 x61 ]) )
150 | data = self . spi . read (4)
151 | self . csn . value (1)
152 | self . write_reg (0 x07 , 0 x40 )
153 | return data

154
155 | def send ( self , data ) :
156 | self . modo_tx ()
157 | self . csn . value (0)
158 | self . spi . write ( bytearray ([0 xA0 ]) + data )
159 | self . csn . value (1)
160 | self . ce . value (1)
161 | time . sleep_us (20)
162 | self . ce . value (0)
163 | time . sleep_ms (5)
164 | self . write_reg (0 x07 , 0 x70 )
165 | self . modo_rx ()

166
167 | def reset ( self ) :
168 | self . ce . value (0)
169 | self . flush_rx ()
170 | self . flush_tx ()
171 | self . write_reg (0 x07 , 0 x70 )
172 | self . modo_rx ()
173 | print (" Radio reiniciado !")

174

175 | # ========================
176 | # FUNÇÕES DOS MOTORES
177 | # ========================
178 | def set_motor ( in_a , in_b , en_pwm , speed ) :
179 | speed = max ( -100 , min (100 , speed ) )
180 | if speed >= 10:
181 | in_a . value (1)
182 | in_b . value (0)
183 | en_pwm . duty_u16 (int ( speed / 100 * 65535) )

APÊNDICE A. Código Fonte do Receptor | 25
184 | elif speed <= -10:
185 | in_a . value (0)
186 | in_b . value (1)
187 | en_pwm . duty_u16 (int (abs ( speed ) / 100 * 65535) )
188 | else :
189 | in_a . value (0)
190 | in_b . value (0)
191 | en_pwm . duty_u16 (0)

192
193 | def drive (x , y ) :
194 | motor_esq = max ( -100 , min (100 , y + x ) )
195 | motor_dir = max ( -100 , min (100 , y - x ) )
196 | set_motor ( in1 , in2 , ena , motor_esq )
197 | set_motor ( in3 , in4 , enb , motor_dir )

198
199 | def parar () :
200 | set_motor ( in1 , in2 , ena , 0)
201 | set_motor ( in3 , in4 , enb , 0)

202

203 | # ========================
204 | # INICIALIZA RÁ DIO
205 | # ========================
206 | radio = NRF24 ( spi , csn , ce )
207 | print (" Receptor pronto , aguardando sinal ... ")
208 | radio . modo_rx () | # Garantir RX mode ao iniciar

209

210 | # Debug : mostrar config inicial
211 | print (" >>> CONFIG INICIAL (RX):")
212 | print ( f" CONFIG : { radio . read_reg (0 x00 ) :#04 x} | EN_RX : { radio . read_reg (0
x02) :#04 x} | CH: { radio . read_reg (0 x05) :#04 x}")

213

214 | # ========================
215 | # LOOP PRINCIPAL
216 | # ========================
217 | TIMEOUT | = 500
218 | TIMEOUT_RESET = 2000

219
220 | ultimo_sinal | = time . ticks_ms ()
221 | primeiro_dump = True

222

223 | while True :
224 | if radio . available () :
225 | data = radio . receive ()
226 | t0 = time . ticks_ms ()

227
228 | y | = data [0] if data [0] < 128 else data [0] - 256
229 | x | = data [1] if data [1] < 128 else data [1] - 256

APÊNDICE A. Código Fonte do Receptor | 26
230 | btn = data [2]

231
232 | drive (x , y )
233 | bomba . value (1 if btn == 0 else 0)
234 | led . value (1)
235 | ultimo_sinal = time . ticks_ms ()

236
237 | umid_pct , umid_dig = ler_umidade ()
238 | t1 = time . ticks_ms ()

239
240 | payload_umid = bytearray ([
241 | umid_pct & 0 xFF ,
242 | umid_dig & 0 xFF ,
243 | 0 xFF ,
244 | 0
245 | ])

246
247 | radio . send ( payload_umid )
248 | time . sleep_ms (50) | # Aumentado de 15 ms → 50 ms para garantir que

resposta chega ao controle

249 | radio . modo_rx () | # Voltar para RX mode
250 | t2 = time . ticks_ms ()

251
252 | print ( f"X: {x} | Y: {y} | BOMBA : {1 if btn == 0 else 0} | "
253 | f" Nivel : { umid_pct }% | { ’ AGUA ’ if umid_dig == 1 else ’SECO
’}")
254 | print ( f" RESPOSTA_TX | Umidade : { umid_pct }% | Tempo ate envio : {
time . ticks_diff (t1 , t0)}ms | Total : { time . ticks_diff (t2 , t0)}ms")

255
256 | if time . ticks_diff ( time . ticks_ms () , ultimo_sinal ) > TIMEOUT :
257 | parar ()
258 | bomba . value (0)
259 | led . value (0)

260
261 | if time . ticks_diff ( time . ticks_ms () , ultimo_sinal ) > TIMEOUT_RESET :
262 | radio . reset ()
263 | ultimo_sinal = time . ticks_ms ()

264
265 | time . sleep_ms (10)

27

# APÊNDICE B – Código Fonte do

# Transmissor

1 | from machine import Pin , ADC , SPI , I2C
2 | import time

3

4 | # ========================
5 | # CONFIG GPIO
6 | # ========================
7 | joy1_x = ADC (27)
8 | joy1_y = ADC (26)
9 | button = Pin (19 , Pin . IN , Pin . PULL_UP )
10 | led | = Pin (25 , Pin . OUT )
11 | umidade_atual = 100

12

13 | # ========================
14 | # I2C + DISPLAY OLED SSD1306
15 | # ========================
16 | i2c = I2C (0 , sda = Pin (0) , scl = Pin (1) , freq =400000)

17
18 | class SSD1306 :
19 | def __init__ ( self , i2c , addr =0 x3C , width =128 , height =64) :
20 | self . i2c | = i2c
21 | self . addr | = addr
22 | self . width | = width
23 | self . height = height
24 | self . pages | = height // 8
25 | self . buffer = bytearray ( self . pages * width )
26 | self . _init_display ()

27
28 | def _cmd ( self , cmd ) :
29 | self . i2c . writeto ( self . addr , bytearray ([0 x00 , cmd ]) )

30
31 | def _init_display ( self ) :
32 | for cmd in [
33 | 0 xAE , 0 x20 , 0 x00 , 0 xB0 , 0 xC8 ,
34 | 0 x00 , 0 x10 , 0 x40 , 0 x81 , 0 xFF ,
35 | 0 xA1 , 0 xA6 , 0 xA8 , 0 x3F , 0 xA4 ,
36 | 0 xD3 , 0 x00 , 0 xD5 , 0 xF0 , 0 xD9 ,
37 | 0 x22 , 0 xDA , 0 x12 , 0 xDB , 0 x20 ,
38 | 0 x8D , 0 x14 , 0 xAF
39 | ]:
40 | self . _cmd ( cmd )

APÊNDICE B. Código Fonte do Transmissor | 28

41
42 | def show ( self ) :
43 | for page in range ( self . pages ) :
44 | self . _cmd (0 xB0 + page )
45 | self . _cmd (0 x00 )
46 | self . _cmd (0 x10 )
47 | self . i2c . writeto ( self . addr ,
48 | | bytearray ([0 x40 ]) + self . buffer [ page * self . width :( page

+ 1) * self . width ])

49
50 | def fill ( self , color ) :
51 | val = 0 xFF if color else 0 x00
52 | self . buffer = bytearray ([ val ] * len( self . buffer ) )

53
54 | def pixel ( self , x , y , color ) :
55 | if 0 <= x < self . width and 0 <= y < self . height :
56 | page = y // 8
57 | bit | = y % 8
58 | idx | = page * self . width + x
59 | if color :
60 | | self . buffer [ idx ] |= (1 << bit )
61 | else :
62 | | self . buffer [ idx ] &= ~(1 << bit )

63
64 | FONT = {
65 | ’ ’: [0 ,0 ,0 ,0 ,0] ,
66 | ’A’: [0 x7E ,0 x09 ,0 x09 ,0 x09 ,0 x7E ] ,
67 | ’B’: [0 x7F ,0 x49 ,0 x49 ,0 x49 ,0 x36 ] ,
68 | ’C’: [0 x3E ,0 x41 ,0 x41 ,0 x41 ,0 x22 ] ,
69 | ’D’: [0 x7F ,0 x41 ,0 x41 ,0 x22 ,0 x1C ] ,
70 | ’E’: [0 x7F ,0 x49 ,0 x49 ,0 x49 ,0 x41 ] ,
71 | ’F’: [0 x7F ,0 x09 ,0 x09 ,0 x09 ,0 x01 ] ,
72 | ’G’: [0 x3E ,0 x41 ,0 x49 ,0 x49 ,0 x7A ] ,
73 | ’H’: [0 x7F ,0 x08 ,0 x08 ,0 x08 ,0 x7F ] ,
74 | ’I’: [0 x41 ,0 x7F ,0 x41 ,0 x00 ,0 x00 ] ,
75 | ’J’: [0 x20 ,0 x40 ,0 x41 ,0 x3F ,0 x01 ] ,
76 | ’K’: [0 x7F ,0 x08 ,0 x14 ,0 x22 ,0 x41 ] ,
77 | ’L’: [0 x7F ,0 x40 ,0 x40 ,0 x40 ,0 x40 ] ,
78 | ’M’: [0 x7F ,0 x02 ,0 x0C ,0 x02 ,0 x7F ] ,
79 | ’N’: [0 x7F ,0 x04 ,0 x08 ,0 x10 ,0 x7F ] ,
80 | ’O’: [0 x3E ,0 x41 ,0 x41 ,0 x41 ,0 x3E ] ,
81 | ’P’: [0 x7F ,0 x09 ,0 x09 ,0 x09 ,0 x06 ] ,
82 | ’Q’: [0 x3E ,0 x41 ,0 x51 ,0 x21 ,0 x5E ] ,
83 | ’R’: [0 x7F ,0 x09 ,0 x19 ,0 x29 ,0 x46 ] ,
84 | ’S’: [0 x46 ,0 x49 ,0 x49 ,0 x49 ,0 x31 ] ,
85 | ’T’: [0 x01 ,0 x01 ,0 x7F ,0 x01 ,0 x01 ] ,
86 | ’U’: [0 x3F ,0 x40 ,0 x40 ,0 x40 ,0 x3F ] ,

APÊNDICE B. Código Fonte do Transmissor | 29
87 | ’V’: [0 x1F ,0 x20 ,0 x40 ,0 x20 ,0 x1F ] ,
88 | ’W’: [0 x3F ,0 x40 ,0 x38 ,0 x40 ,0 x3F ] ,
89 | ’X’: [0 x63 ,0 x14 ,0 x08 ,0 x14 ,0 x63 ] ,
90 | ’Y’: [0 x07 ,0 x08 ,0 x70 ,0 x08 ,0 x07 ] ,
91 | ’Z’: [0 x61 ,0 x51 ,0 x49 ,0 x45 ,0 x43 ] ,
92 | ’0’: [0 x3E ,0 x51 ,0 x49 ,0 x45 ,0 x3E ] ,
93 | ’1’: [0 x00 ,0 x42 ,0 x7F ,0 x40 ,0 x00 ] ,
94 | ’2’: [0 x42 ,0 x61 ,0 x51 ,0 x49 ,0 x46 ] ,
95 | ’3’: [0 x21 ,0 x41 ,0 x45 ,0 x4B ,0 x31 ] ,
96 | ’4’: [0 x18 ,0 x14 ,0 x12 ,0 x7F ,0 x10 ] ,
97 | ’5’: [0 x27 ,0 x45 ,0 x45 ,0 x45 ,0 x39 ] ,
98 | ’6’: [0 x3C ,0 x4A ,0 x49 ,0 x49 ,0 x30 ] ,
99 | ’7’: [0 x01 ,0 x71 ,0 x09 ,0 x05 ,0 x03 ] ,
100 | ’8’: [0 x36 ,0 x49 ,0 x49 ,0 x49 ,0 x36 ] ,
101 | ’9’: [0 x06 ,0 x49 ,0 x49 ,0 x29 ,0 x1E ] ,
102 | ’:’: [0 x00 ,0 x36 ,0 x36 ,0 x00 ,0 x00 ] ,
103 | ’-’: [0 x08 ,0 x08 ,0 x08 ,0 x08 ,0 x08 ] ,
104 | ’%’: [0 x23 ,0 x13 ,0 x08 ,0 x64 ,0 x62 ] ,
105 | }

106
107 | def text ( self , string , x , y , color =1) :
108 | for ch in string . upper () :
109 | glyph = self . FONT . get ( ch , self . FONT [’ ’])
110 | for col_idx , col in enumerate ( glyph ) :
111 | for row in range (8) :
112 | self . pixel ( x + col_idx , y + row , ( col >> row ) & 1 if
| color else 0)
113 | x += 6
114 | if x > self . width :
115 | break

116

117 | # Inicializa display
118 | display = SSD1306 ( i2c )
119 | display . fill (0)
120 | display . text (" CARRO ", 30 , 20)
121 | display . text (" BOMBEIRO ", 16 , 36)
122 | display . show ()
123 | time . sleep (2)

124

125 | # ========================
126 | # SPI NRF24L01
127 | # ========================
128 | spi = SPI (0 ,
129 | baudrate =1000000 ,
130 | polarity =0 ,
131 | phase =0 ,
132 | sck = Pin (6) ,

APÊNDICE B. Código Fonte do Transmissor | 30
133 | mosi = Pin (7) ,
134 | miso = Pin (4) )
135 | csn = Pin (5 , Pin . OUT )
136 | ce | = Pin (9 , Pin . OUT )

137

138 | # ========================
139 | # ENDERE ÇOS
140 | # ========================
141 | ADDR_CONTROLE = [0 xE7 ,0 xE7 ,0 xE7 ,0 xE7 ,0 xE7 ]
142 | ADDR_CARRO | = [0 xC2 ,0 xC2 ,0 xC2 ,0 xC2 ,0 xC2 ]

143

144 | # ========================
145 | # DRIVER NRF24L01
146 | # ========================
147 | class NRF24 :
148 | def __init__ ( self , spi , csn , ce ) :
149 | self . spi = spi
150 | self . csn = csn
151 | self . ce | = ce
152 | self . csn . value (1)
153 | self . ce . value (0)
154 | self . init_tx ()

155
156 | def write_reg ( self , reg , value ) :
157 | self . csn . value (0)
158 | self . spi . write ( bytearray ([0 x20 | reg , value ]) )
159 | self . csn . value (1)

160
161 | def read_reg ( self , reg ) :
162 | self . csn . value (0)
163 | self . spi . write ( bytearray ([ reg & 0 x1F ]) )
164 | result = self . spi . read (1)
165 | self . csn . value (1)
166 | return result [0]

167
168 | def set_addr ( self , pipe_reg , addr_bytes ) :
169 | self . csn . value (0)
170 | self . spi . write ( bytearray ([0 x20 | pipe_reg ]) + bytearray (

addr_bytes ) )

171 | self . csn . value (1)

172
173 | def flush_rx ( self ) :
174 | self . csn . value (0)
175 | self . spi . write ( bytearray ([0 xE2 ]) )
176 | self . csn . value (1)

177
178 | def flush_tx ( self ) :

APÊNDICE B. Código Fonte do Transmissor | 31
179 | self . csn . value (0)
180 | self . spi . write ( bytearray ([0 xE1 ]) )
181 | self . csn . value (1)

182
183 | def init_tx ( self ) :
184 | time . sleep_ms (100)
185 | self . write_reg (0 x00 , 0 x0A )
186 | self . write_reg (0 x01 , 0 x00 )
187 | self . write_reg (0 x02 , 0 x01 )
188 | self . write_reg (0 x05 , 0 x02 )
189 | self . write_reg (0 x06 , 0 x26 )
190 | self . set_addr (0 x10 , ADDR_CARRO )
191 | self . set_addr (0 x0A , ADDR_CONTROLE )
192 | self . write_reg (0 x11 , 4)
193 | self . flush_rx ()
194 | self . flush_tx ()
195 | self . write_reg (0 x07 , 0 x70 )

196
197 | def modo_rx ( self ) :
198 | self . ce . value (0)
199 | self . write_reg (0 x00 , 0 x0B )
200 | self . write_reg (0 x02 , 0 x01 )
201 | self . set_addr (0 x0A , ADDR_CONTROLE )
202 | self . flush_rx ()
203 | self . write_reg (0 x07 , 0 x70 )
204 | self . ce . value (1)
205 | time . sleep_us (150)

206
207 | def modo_tx ( self ) :
208 | self . ce . value (0)
209 | self . write_reg (0 x00 , 0 x0A )
210 | self . flush_tx ()
211 | time . sleep_us (150)

212
213 | def send ( self , data ) :
214 | self . modo_tx ()
215 | self . csn . value (0)
216 | self . spi . write ( bytearray ([0 xA0 ]) + data )
217 | self . csn . value (1)
218 | self . ce . value (1)
219 | time . sleep_us (15)
220 | self . ce . value (0)
221 | time . sleep_ms (3)
222 | self . write_reg (0 x07 , 0 x70 )
223 | self . modo_rx ()

224
225 | def available ( self ) :

APÊNDICE B. Código Fonte do Transmissor | 32
226 | status = self . read_reg (0 x07 )
227 | if status & 0 x10 :
228 | self . write_reg (0 x07 , 0 x70 )
229 | self . flush_rx ()
230 | return ( status & 0 x40 ) != 0

231
232 | def receive ( self ) :
233 | self . csn . value (0)
234 | self . spi . write ( bytearray ([0 x61 ]) )
235 | data = self . spi . read (4)
236 | self . csn . value (1)
237 | self . write_reg (0 x07 , 0 x40 )
238 | return data

239
240 | def dump_regs ( self ) :
241 | print (" === DUMP REGISTRADORES === ")
242 | print ( f" CONFIG | (0 x00 ): { self . read_reg (0 x00) :#04 x}")
243 | print ( f" EN_AA | (0 x01 ): { self . read_reg (0 x01) :#04 x}")
244 | print ( f" EN_RXADDR (0 x02 ): { self . read_reg (0 x02) :#04 x}")
245 | print ( f" RF_CH | (0 x05 ): { self . read_reg (0 x05) :#04 x}")
246 | print ( f" RF_SETUP | (0 x06 ): { self . read_reg (0 x06) :#04 x}")
247 | print ( f" STATUS | (0 x07 ): { self . read_reg (0 x07) :#04 x}")
248 | print ( f" RX_PW_P0 | (0 x11 ): { self . read_reg (0 x11) :#04 x}")
249 | self . csn . value (0)
250 | self . spi . write ( bytearray ([0 x10 ]) )
251 | tx_addr = self . spi . read (5)
252 | self . csn . value (1)
253 | print ( f" TX_ADDR | (0 x10 ): {[ hex (b) for b in tx_addr ]}")
254 | self . csn . value (0)
255 | self . spi . write ( bytearray ([0 x0A ]) )
256 | rx0_addr = self . spi . read (5)
257 | self . csn . value (1)
258 | print ( f" RX_ADDR_P0 (0 x0A ): {[ hex (b) for b in rx0_addr ]}")
259 | print (" ========================== ")

260

261 | # ========================
262 | # INICIALIZA RÁ DIO
263 | # ========================
264 | radio = NRF24 ( spi , csn , ce )
265 | print (" >>> DUMP INICIAL ( modo TX):")
266 | radio . dump_regs ()

267

268 | # ========================
269 | # FUNÇÕES
270 | # ========================
271 | def read_joystick ( adc ) :
272 | return adc . read_u16 ()

APÊNDICE B. Código Fonte do Transmissor | 33

273
274 | def normalize ( value ) :
275 | return int (( value - 32768) / 32768 * 100)

276

277 | # ========================
278 | # LOOP PRINCIPAL
279 | # ========================
280 | INTERVALO_TX = 80
281 | JANELA_RX | = 25

282
283 ultimo_tx = time . ticks_ms ()

284

285 while True :

286
287 | if time . ticks_diff ( time . ticks_ms () , ultimo_tx ) >= INTERVALO_TX :

288
289 | x_norm = - normalize ( read_joystick ( joy1_x ) )
290 | y_norm = - normalize ( read_joystick ( joy1_y ) )

291
292 | btn = button . value ()

293
294 | led . value (1 if btn == 0 else 0)

295
296 | # Determina status ( AGUA se >= 30% , SECO abaixo )
297 | umidade_status = " AGUA " if umidade_atual >= 30 else " SECO "

298
299 | payload = bytearray ([
300 | x_norm & 0 xFF ,
301 | y_norm & 0 xFF ,
302 | btn ,
303 | 0
304 | ])

305
306 | radio . send ( payload )

307
308 | ultimo_tx = time . ticks_ms ()

309
310 | deadline = time . ticks_add ( time . ticks_ms () , JANELA_RX )
311 | recebeu | = False

312
313 | while time . ticks_diff ( deadline , time . ticks_ms () ) > 0:
314 | if radio . available () :
315 | resp = radio . receive ()
316 | if resp [2] == 0 xFF :
317 | print ("RX OK | Umidade real :", resp [0])
318 | recebeu = True
319 | break

APÊNDICE B. Código Fonte do Transmissor | 34
320 | time . sleep_ms (1)

321

322 | if not recebeu :
323 | print ( f"Sem resposta RF | Umidade SIM: { umidade_atual }% [{
| umidade_status }]")

324

325 | # ---- Atualiza OLED ----
326 | display . fill (0)

327
328 | display . text (" CARRO BOMBEIRO ", 4 , 0)

329
330 | display . text ("X:" + str ( x_norm ) , 0 , 18)
331 | display . text ("Y:" + str ( y_norm ) , 0 , 30)

332
333 | display . text (
334 | " BTN:" + ("ON" if btn == 0 else "OFF ") ,
335 | 0 , 42
336 | )

337
338 | display . text (
339 | "UM:" + str ( umidade_atual ) + "% " + umidade_status ,
340 | 0 , 54
341 | )

342
343 | display . show ()

344
345 | time . sleep_ms (1)

35

# APÊNDICE C – Modificação Técnica da

# Bomba d’Água

## A Figura 15 detalha a alteração realizada no circuito de acionamento da bomba

d’água para permitir o controle via transistor, garantindo o acionamento adequado a partir do sinal de controle do microcontrolador.

## Figura 15 – Esquema da Modificação da Bomba d’Água


## Fonte: Os autores (2026)

# Anexos

37

# ANEXO A – Esquema Elétrico do Carro

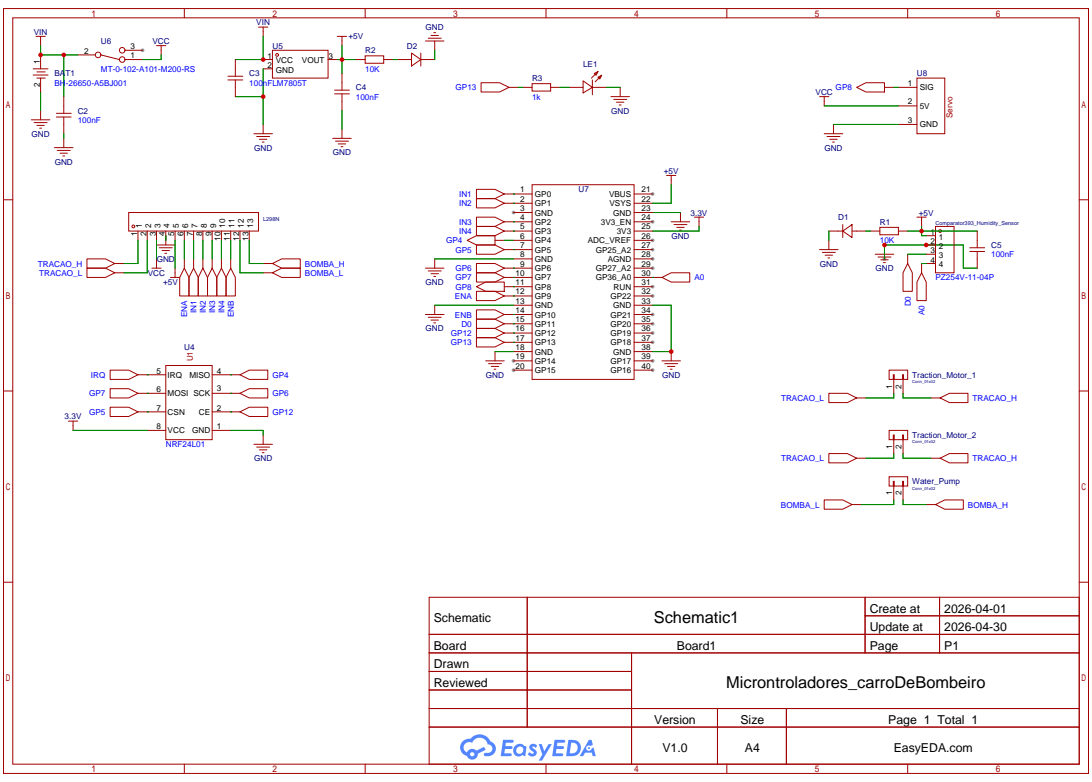
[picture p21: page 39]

Schematic | Schematic1 | Create at | 2026-04-01

Update at | 2026-04-30

Board | Board1 | Page | P1
Drawn | | Microntroladores_carroDeBombeiro
Reviewed

Version | Size | Page 1 Total 1
V1.0 | A4 | EasyEDA.com

39

# ANEXO B – Layout da PCB do Carro

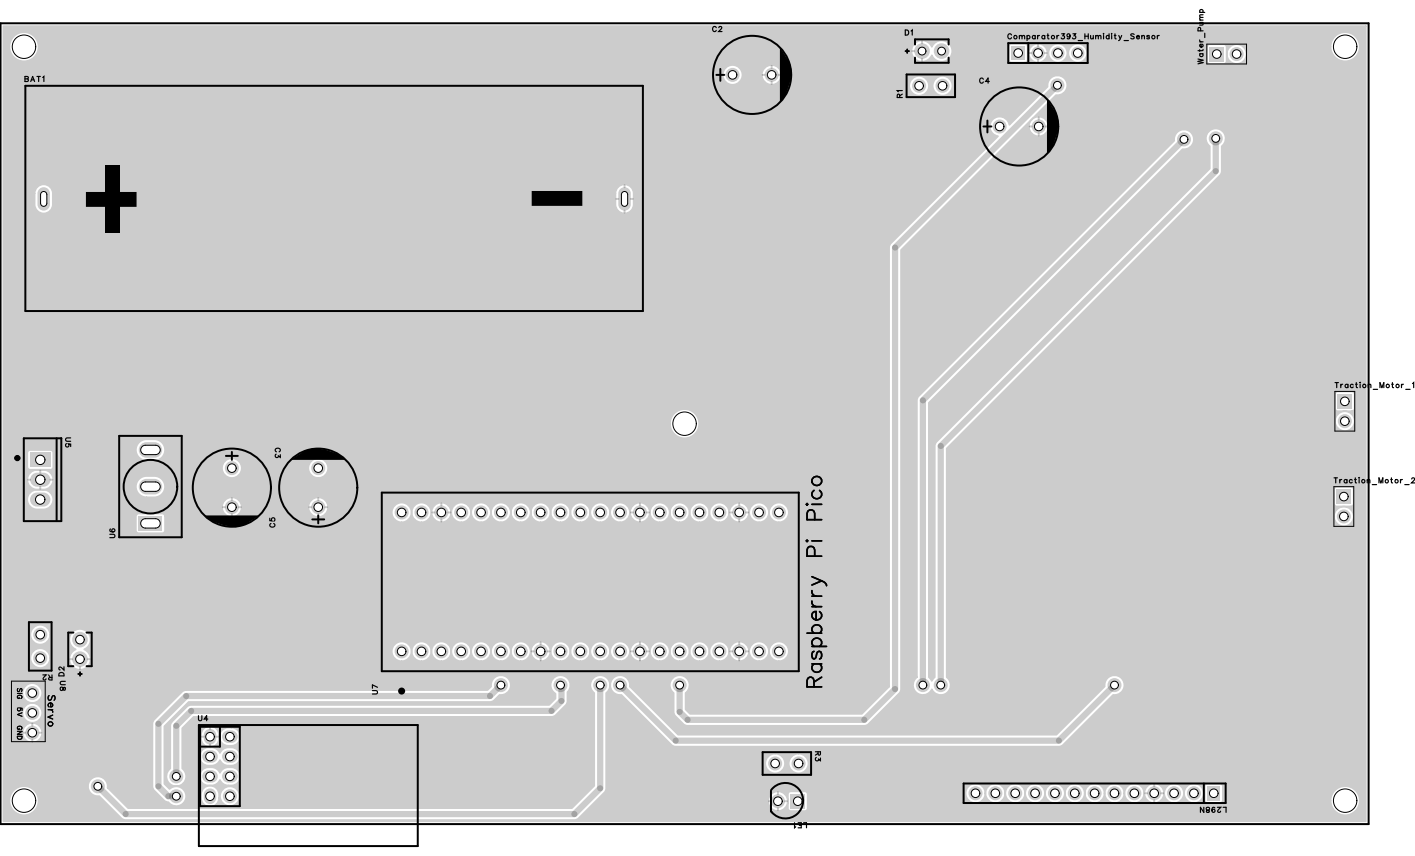
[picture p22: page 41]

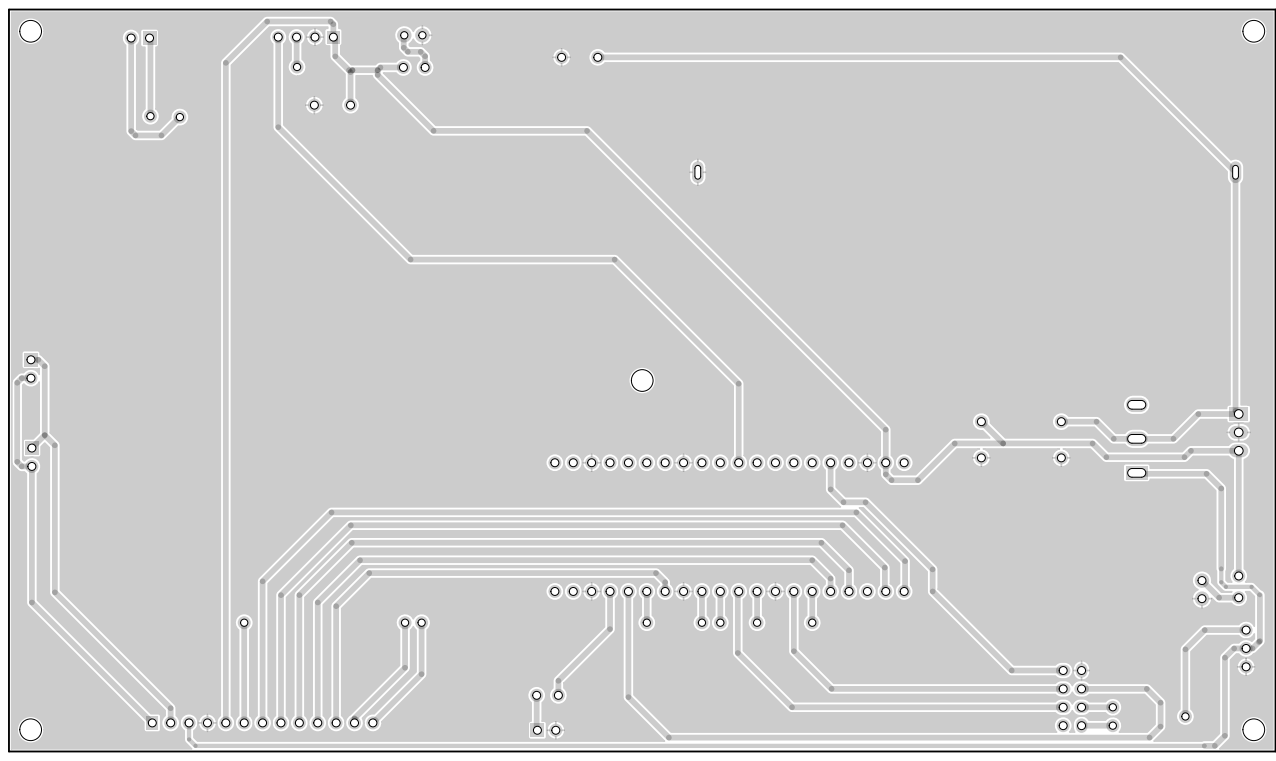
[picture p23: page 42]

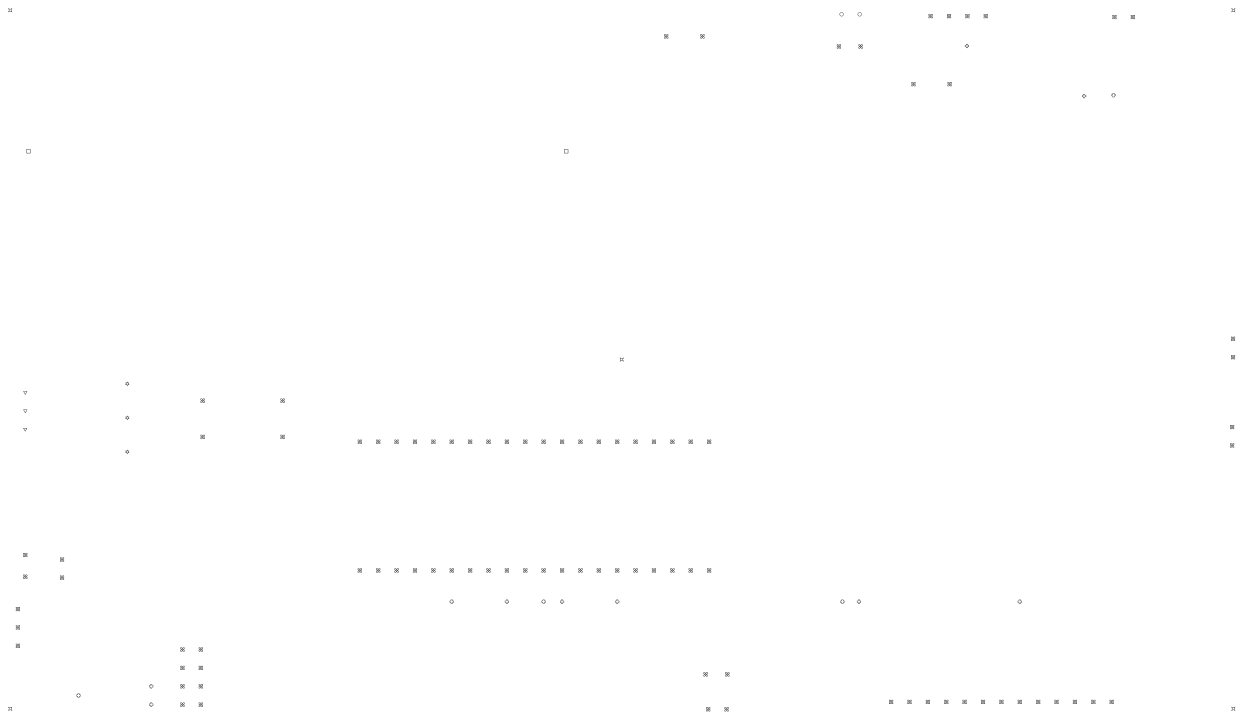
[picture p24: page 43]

43

# ANEXO C – Esquema Elétrico do Controle

TITLE:; Sheet_1; REV: 1.0; Date:; Sheet: 1/1; Rapberry Pi Pico; PICO1; GND; 22 GND; 27 GND; 29 RUN; 30 GP26-ADC0; 31 GP27-ADC1; 32 GND; 33 GP28-ADC2; 3V3(OUT) 36; 37 GND; 38 VSYS; 39 VBUS; GRD; VCC; VRX; 3 VRY 4; 1x2-compact-connector; CON1; NRFL01 COPY; MISO; SCK; IRQ; MOSI 6; CSN; GPIO5; GPIO7; GPIO4; GPIO6; GPIO9; ADC1; ADC0; GPIO19

Arduino Joystick KY-023

3mm Green TH LED 5600

Company: Your Company

Drawn By: jgfioruci

45

# ANEXO D – Layout da PCB do Controle


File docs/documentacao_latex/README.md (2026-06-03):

# Documentação LaTeX - Carro Bombeiro Teleoprado

Este diretório contém os arquivos fonte para a geração da documentação técnica do projeto seguindo as normas da ABNT.

## Estrutura de Arquivos

- `main.tex`: Arquivo principal que contém a estrutura do documento e o conteúdo das seções.
- `referencias.bib`: Arquivo de bibliografia no formato BibTeX.

## Requisitos para Compilação

Para compilar estes arquivos e gerar o PDF, você precisará de uma distribuição LaTeX instalada (como MiKTeX ou TeX Live) e da classe `abntex2`.

### Comandos de Compilação

1. `pdflatex main.tex`
2. `bibtex main`
3. `pdflatex main.tex`
4. `pdflatex main.tex`

Ou utilize um editor como TeXstudio, VSCode (com extensão LaTeX Workshop) ou o serviço online Overleaf.

## Notas

Os nomes dos integrantes e da instituição estão como placeholders `[Nome ...]` no arquivo `main.tex`. Lembre-se de editá-los antes da versão final.

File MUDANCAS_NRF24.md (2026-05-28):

# Adaptação para Biblioteca NRF24L01

## Resumo das Mudanças

Ambos os códigos foram adaptados para usar a biblioteca `nrf24l01.py` profissional em vez da implementação customizada. Isso simplifica o código e melhora a confiabilidade.

## Principais Mudanças

### 1. **Importação da Biblioteca**
```python
from nrf24l01 import NRF24L01, POWER_3, SPEED_1M
```

### 2. **Inicialização do Rádio**

**Antes:**
```python
radio = NRF24(spi, csn, ce)  # Classe customizada
```

**Depois:**
```python
radio = NRF24L01(spi, csn, ce, channel=2, payload_size=4)
radio.set_power_speed(POWER_3, SPEED_1M)
```

### 3. **Métodos Utilizados da Biblioteca**

| Método | Função |
|---|---|
| `open_tx_pipe(address)` | Configura o endereço para transmissão |
| `open_rx_pipe(pipe_id, address)` | Configura o endereço para recepção |
| `send(data)` | Envia dados (timeout de 500ms por padrão) |
| `recv()` | Recebe dados |
| `any()` | Verifica se há dados disponíveis |
| `start_listening()` | Ativa modo RX |
| `stop_listening()` | Desativa modo RX |

### 4. **Fluxo de Comunicação**

#### Controle (TX/RX cíclico):
1. `stop_listening()` - Sai do modo RX
2. `send(payload)` - Envia comando para o carro
3. `start_listening()` - Volta ao modo RX
4. Aguarda resposta com `radio.any()`
5. Recebe com `radio.recv()`

#### Carro (RX contínuo com TX sob demanda):
1. `start_listening()` - Ativa modo RX na inicialização
2. Aguarda comandos com `radio.any()`
3. Recebe com `radio.recv()`
4. `stop_listening()` - Sai do modo RX para enviar
5. `send(payload_umidade)` - Envia resposta
6. `start_listening()` - Volta ao modo RX

### 5. **Display OLED no Controle**

O display agora mostra os dados de umidade recebidos do carro em tempo real:
- **Umidade %**: Porcentagem do nível de água
- **AGUA/SECO**: Status do sensor digital

Formato da tela:
```
CARRO BOMBEIRO
X:XX
Y:XX
BTN:ON/OFF
UM:XX% AGUA/SECO
```

### 6. **Protocolo de Comunicação**

**Payload enviado pelo controle para o carro (4 bytes):**
- `[0]` = X normalizado (-100 a 100)
- `[1]` = Y normalizado (-100 a 100)
- `[2]` = Botão (0=pressionado, 1=solto)
- `[3]` = Reservado (0)

**Payload enviado pelo carro para o controle (4 bytes):**
- `[0]` = Nível de umidade (0-100%)
- `[1]` = Status digital de água (1=detecção, 0=sem detecção)
- `[2]` = Marcador (0xFF)
- `[3]` = Reservado (0)

## Vantagens da Nova Implementação

✅ **Código mais limpo**: Menos linhas de código, sem necessidade de gerenciar registradores SPI manualmente

✅ **Melhor tratamento de erros**: A biblioteca trata timeouts automaticamente

✅ **Integração com display**: O controle mostra dados de umidade em tempo real

✅ **Comunicação bidirecional simples**: Alternar entre TX/RX é mais intuitivo

✅ **Compatibilidade**: Mesmos endereços e configurações de canal

## Teste de Comunicação

Ambos os códigos estão prontos para usar. O carro aguardará pelo controle, e o controle enviará comandos periodicamente (a cada 100ms). A umidade será exibida no display OLED do controle.

### Console esperado no carro:
```
Receptor pronto, aguardando sinal...
X: 50 | Y: -30 | BOMBA: 0 | Umidade: 75% | AGUA
```

### Console esperado no controle:
```
Aguardando dados...
X: 50 Y: -30 BTN: OFF | Umidade: 75 % AGUA
```

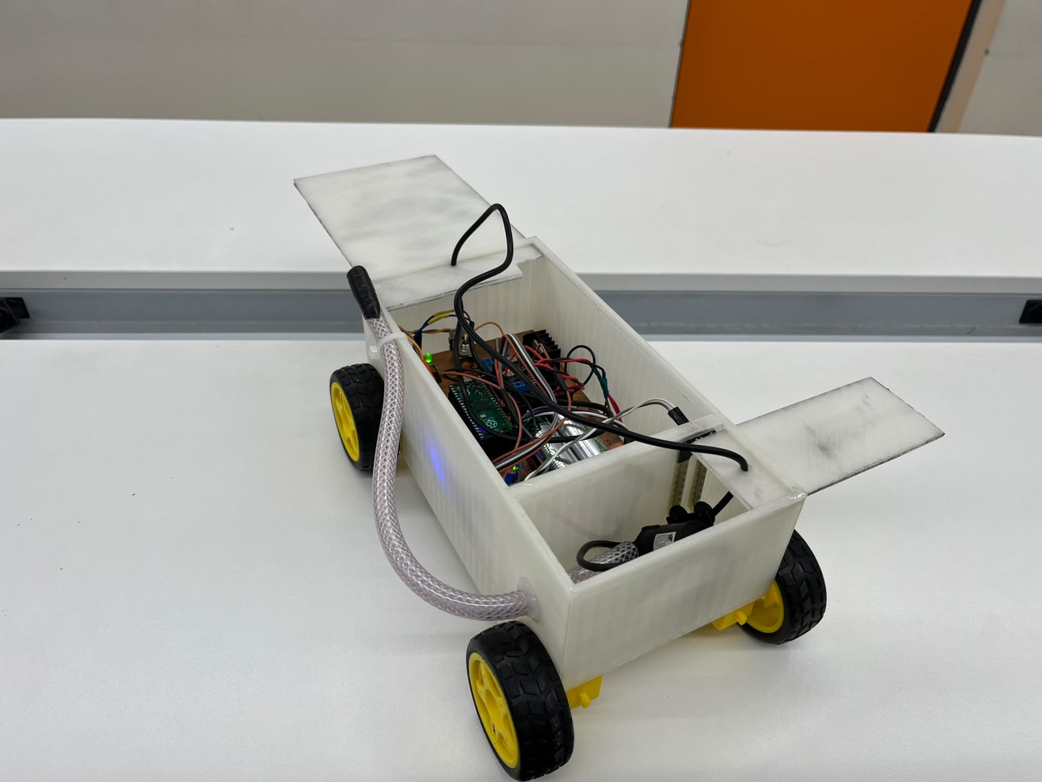
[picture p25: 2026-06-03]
Fotos carro/Foto do carro com a eletronica aberta 2.jpeg

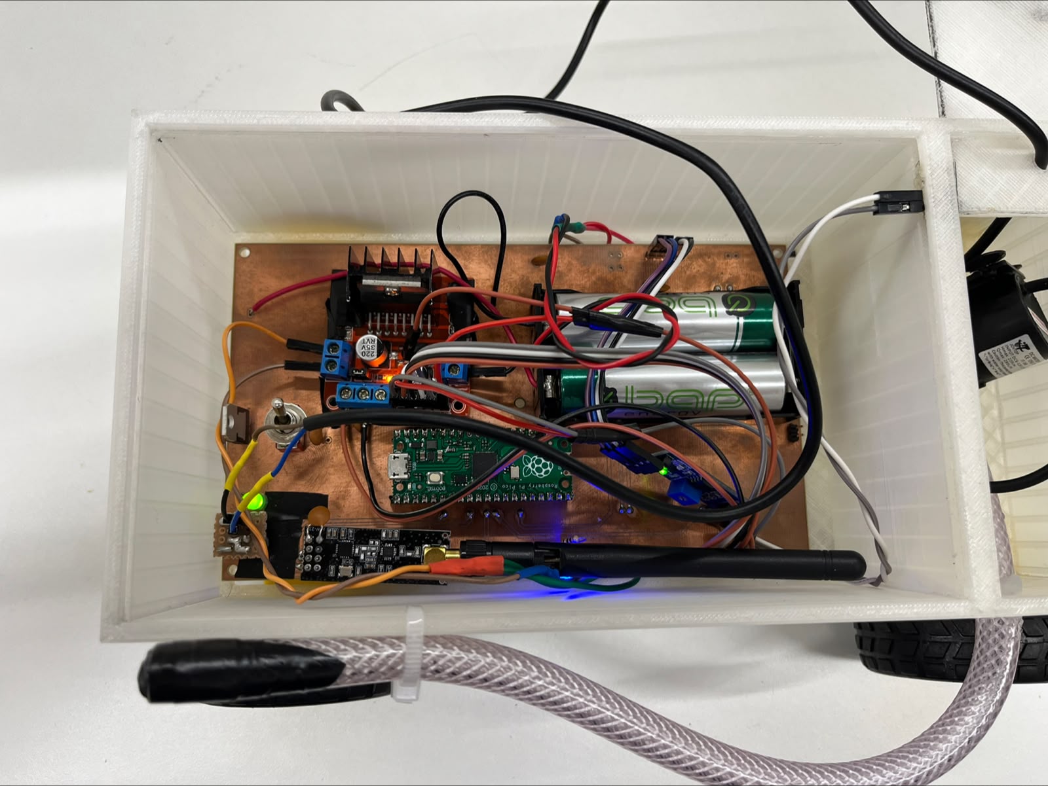
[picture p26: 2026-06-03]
Fotos carro/Foto do carro com a eletronica aberta perto.jpeg

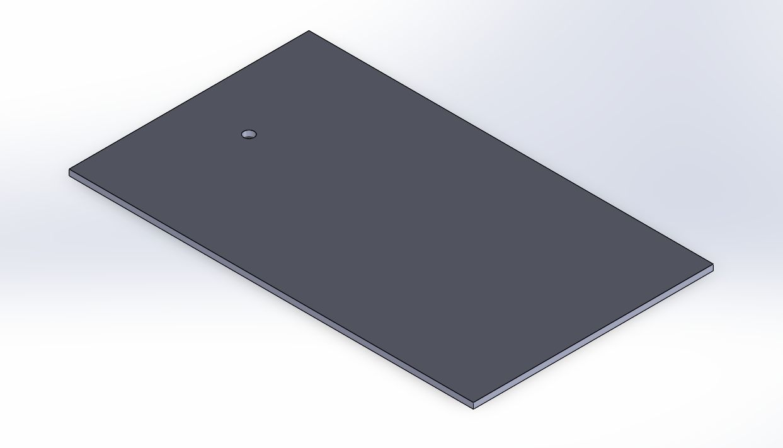
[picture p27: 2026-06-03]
Modelos 3D Solid/Tampa Controle.png

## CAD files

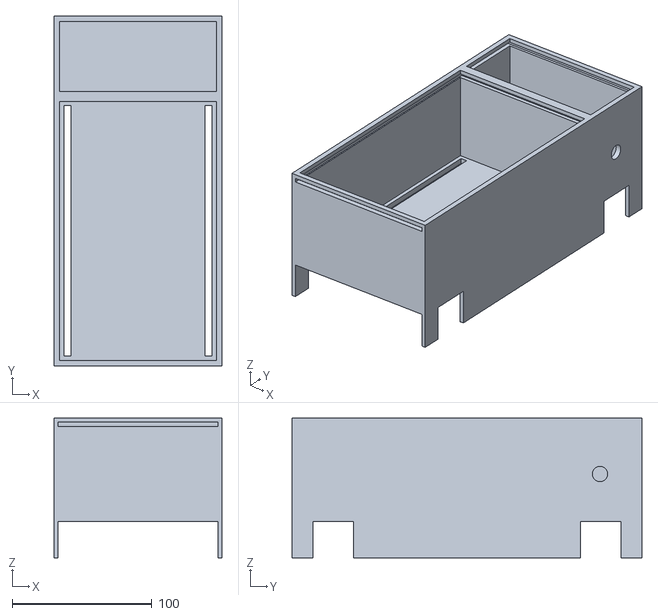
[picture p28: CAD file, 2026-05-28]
Modelo 3D STL/Carro.STL
120.0 x 250.0 x 100.0

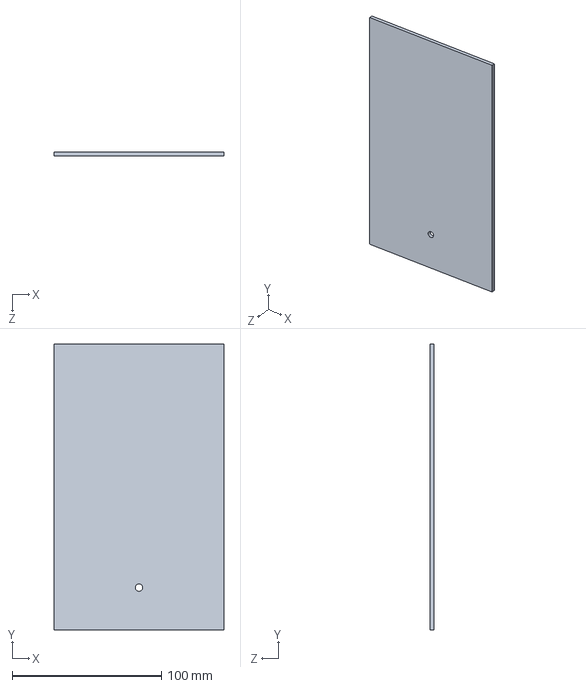
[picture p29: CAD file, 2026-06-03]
Modelos 3D Solid/Tampa Controle.SLDPRT
113.8 x 191.8 x 2.80 mm

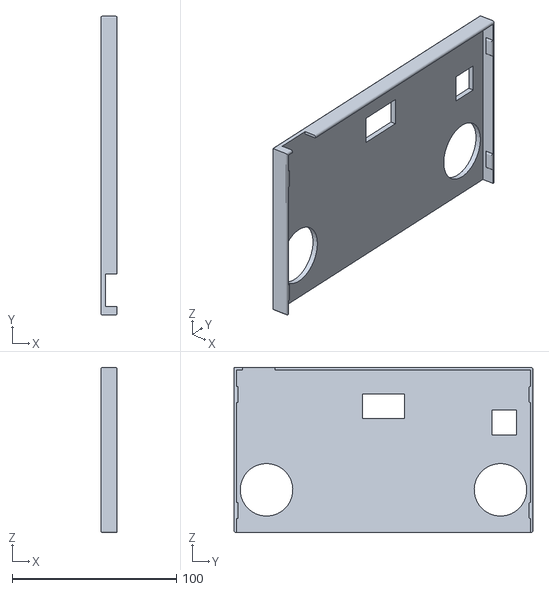
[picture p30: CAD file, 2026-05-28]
Modelo 3D STL/Controle Tampa.STL
10.0 x 182.0 x 100.5

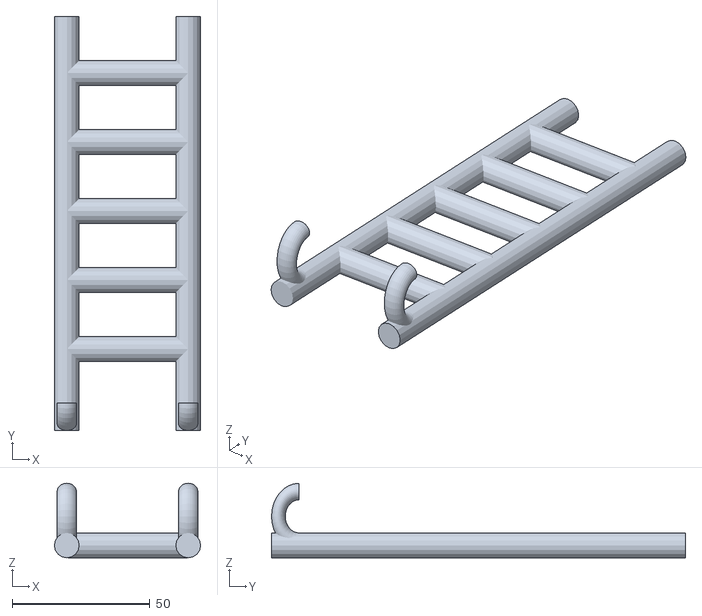
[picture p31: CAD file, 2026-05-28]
Modelo 3D STL/Escada.stl
53.0 x 150.0 x 27.0

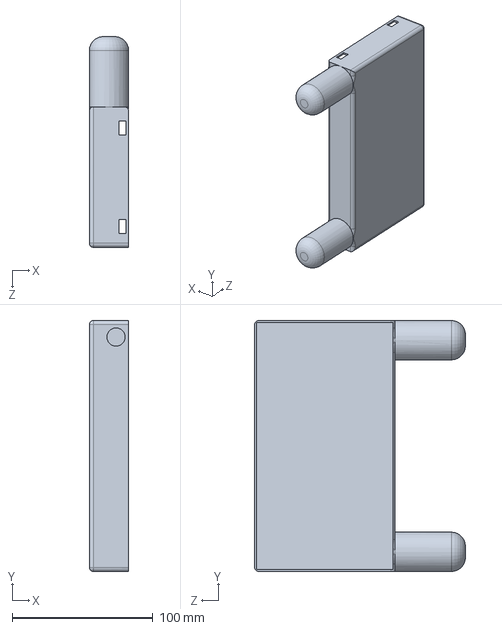
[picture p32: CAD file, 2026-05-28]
Modelos 3D Solid/Controle Base.SLDPRT
28.0 x 178.5 x 150.0 mm

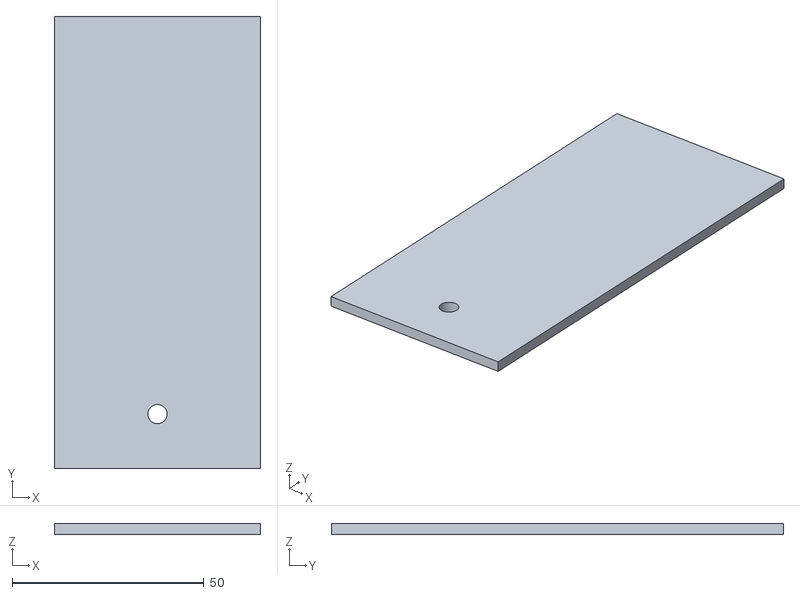
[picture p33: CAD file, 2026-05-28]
Modelo 3D STL/tampa agua.STL
53.8 x 117.8 x 2.80

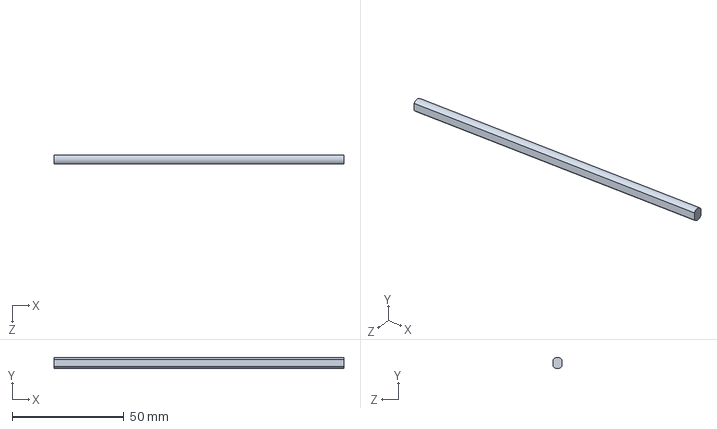
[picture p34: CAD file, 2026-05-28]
Modelos 3D Solid/Barra dianteira.SLDPRT
130.0 x 4.97 x 4.00 mm

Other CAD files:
Modelos 3D Solid/Controle Tampa.SLDPRT
Modelo 3D STL/Controle Base.STL
Modelos 3D Solid/Carro.SLDPRT
Modelo 3D STL/Tampa Controle.STL
Modelos 3D Solid/tampa agua.SLDPRT

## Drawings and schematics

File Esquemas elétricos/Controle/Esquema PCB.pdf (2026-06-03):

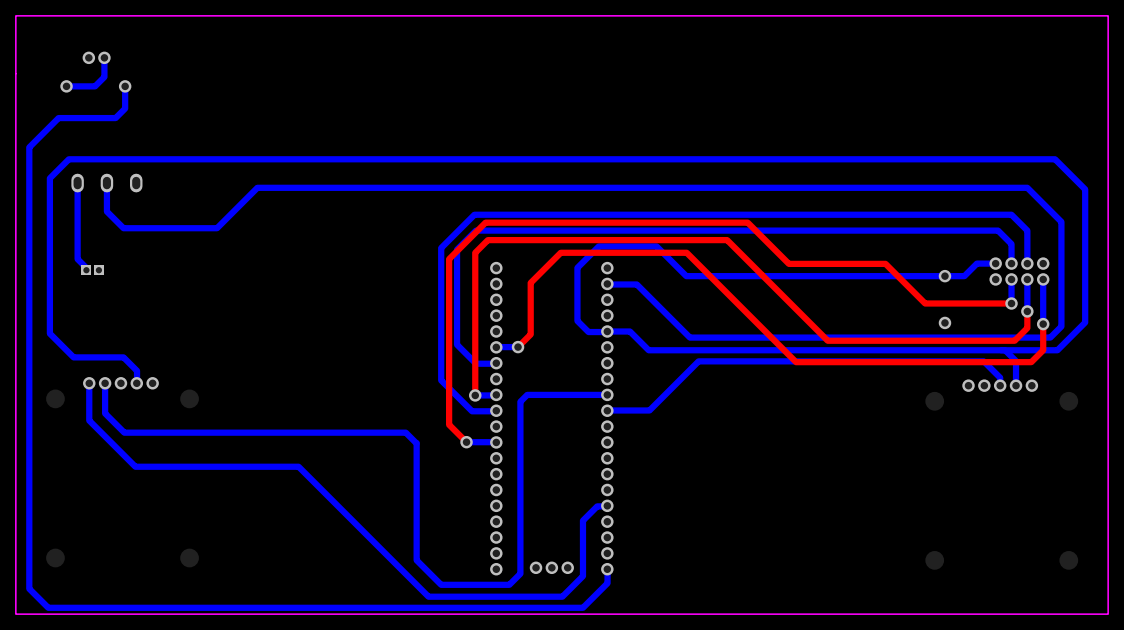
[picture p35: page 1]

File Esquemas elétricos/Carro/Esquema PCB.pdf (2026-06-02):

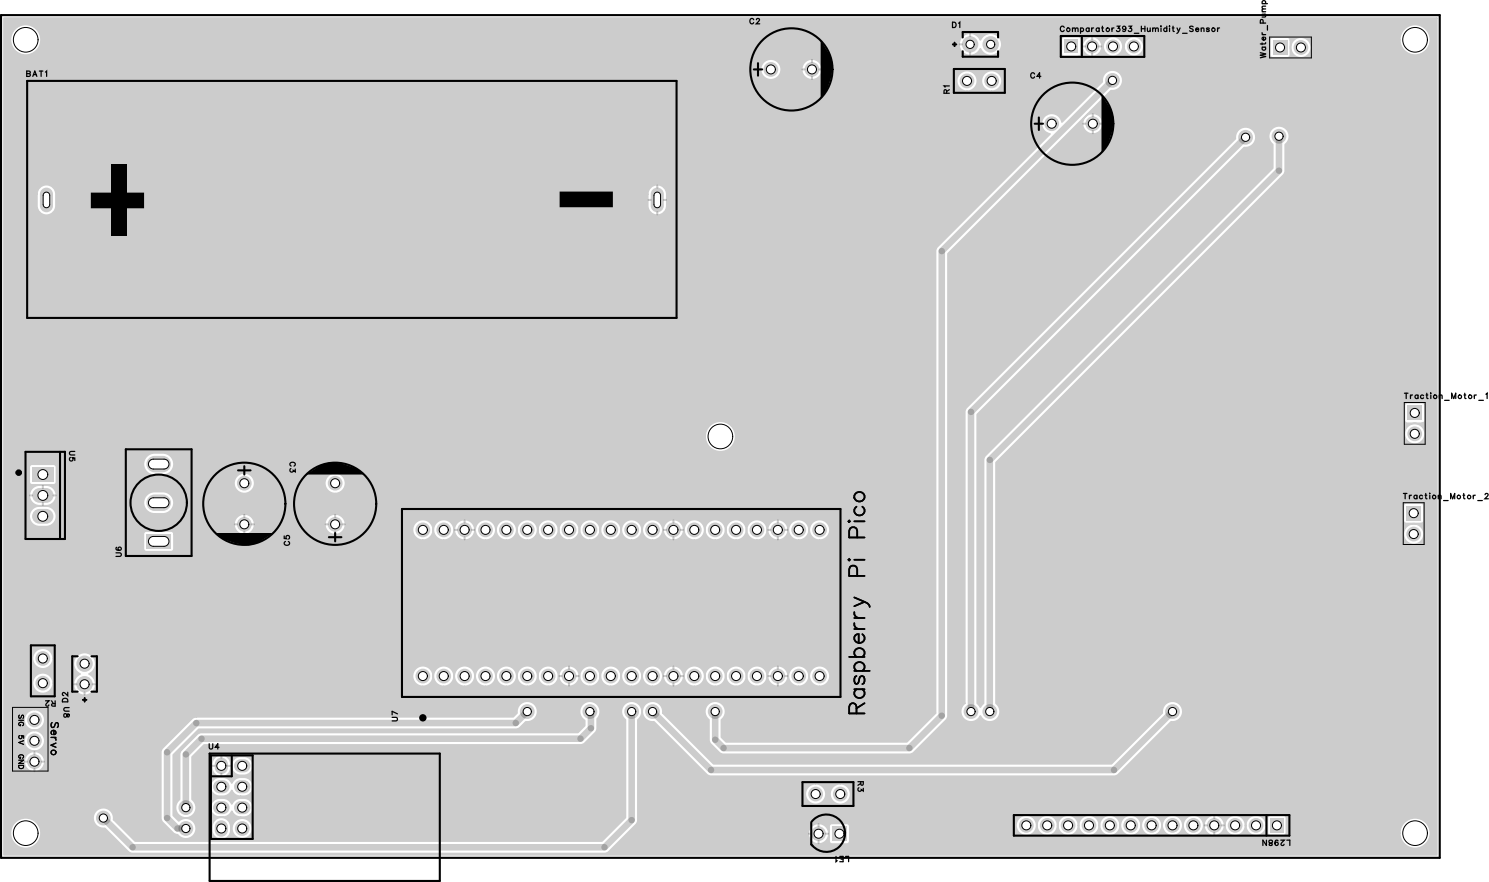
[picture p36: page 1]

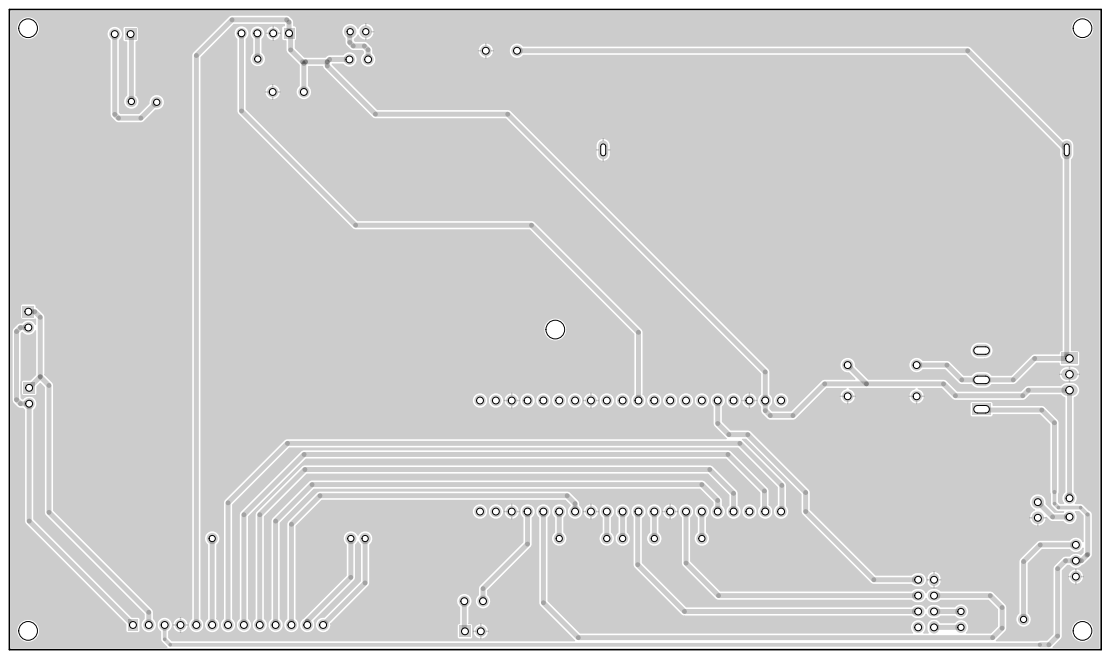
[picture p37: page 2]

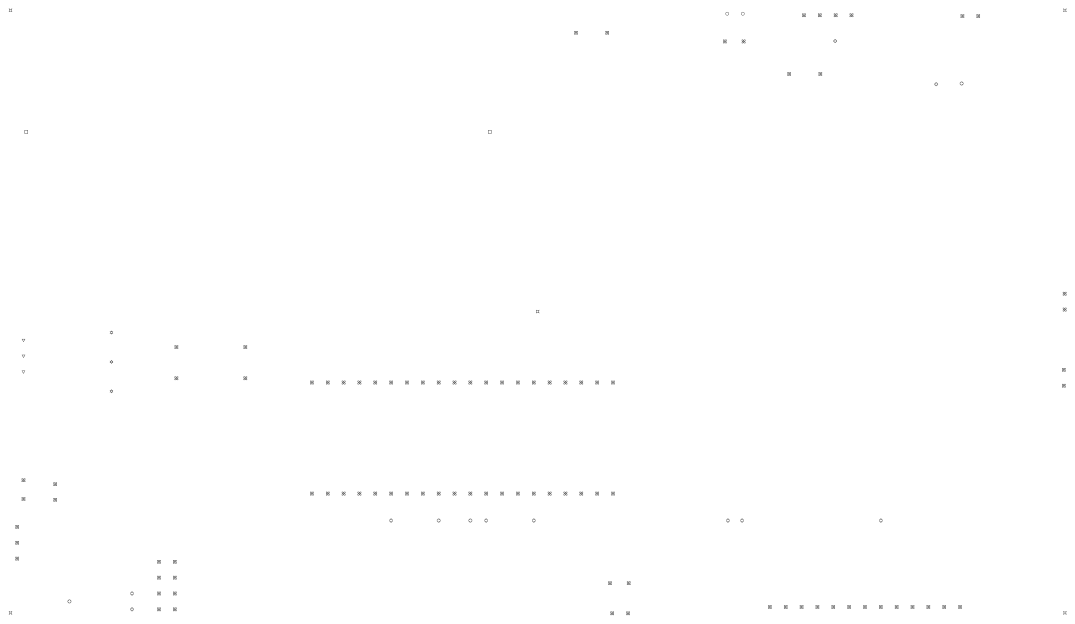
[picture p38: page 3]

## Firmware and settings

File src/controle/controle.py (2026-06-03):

from machine import Pin, ADC, SPI, I2C
import time

# ========================
# CONFIG GPIO
# ========================
joy1_x = ADC(27)
joy1_y = ADC(26)
button = Pin(19, Pin.IN, Pin.PULL_UP)
led    = Pin(25, Pin.OUT)
umidade_atual = 100

# ========================
# I2C + DISPLAY OLED SSD1306
# ========================
i2c = I2C(0, sda=Pin(0), scl=Pin(1), freq=400000)

class SSD1306:
    def __init__(self, i2c, addr=0x3C, width=128, height=64):
        self.i2c    = i2c
        self.addr   = addr
        self.width  = width
        self.height = height
        self.pages  = height // 8
        self.buffer = bytearray(self.pages * width)
        self._init_display()

    def _cmd(self, cmd):
        self.i2c.writeto(self.addr, bytearray([0x00, cmd]))

    def _init_display(self):
        for cmd in [
            0xAE, 0x20, 0x00, 0xB0, 0xC8,
            0x00, 0x10, 0x40, 0x81, 0xFF,
            0xA1, 0xA6, 0xA8, 0x3F, 0xA4,
            0xD3, 0x00, 0xD5, 0xF0, 0xD9,
            0x22, 0xDA, 0x12, 0xDB, 0x20,
            0x8D, 0x14, 0xAF
        ]:
            self._cmd(cmd)

    def show(self):
        for page in range(self.pages):
            self._cmd(0xB0 + page)
            self._cmd(0x00)
            self._cmd(0x10)
            self.i2c.writeto(self.addr,
                bytearray([0x40]) + self.buffer[page * self.width:(page + 1) * self.width])

    def fill(self, color):
        val = 0xFF if color else 0x00
        self.buffer = bytearray([val] * len(self.buffer))

    def pixel(self, x, y, color):
        if 0 <= x < self.width and 0 <= y < self.height:
            page = y // 8
            bit  = y % 8
            idx  = page * self.width + x
            if color:
                self.buffer[idx] |= (1 << bit)
            else:
                self.buffer[idx] &= ~(1 << bit)

    FONT = {
        ' ': [0,0,0,0,0],
        'A': [0x7E,0x09,0x09,0x09,0x7E],
        'B': [0x7F,0x49,0x49,0x49,0x36],
        'C': [0x3E,0x41,0x41,0x41,0x22],
        'D': [0x7F,0x41,0x41,0x22,0x1C],
        'E': [0x7F,0x49,0x49,0x49,0x41],
        'F': [0x7F,0x09,0x09,0x09,0x01],
        'G': [0x3E,0x41,0x49,0x49,0x7A],
        'H': [0x7F,0x08,0x08,0x08,0x7F],
        'I': [0x41,0x7F,0x41,0x00,0x00],
        'J': [0x20,0x40,0x41,0x3F,0x01],
        'K': [0x7F,0x08,0x14,0x22,0x41],
        'L': [0x7F,0x40,0x40,0x40,0x40],
        'M': [0x7F,0x02,0x0C,0x02,0x7F],
        'N': [0x7F,0x04,0x08,0x10,0x7F],
        'O': [0x3E,0x41,0x41,0x41,0x3E],
        'P': [0x7F,0x09,0x09,0x09,0x06],
        'Q': [0x3E,0x41,0x51,0x21,0x5E],
        'R': [0x7F,0x09,0x19,0x29,0x46],
        'S': [0x46,0x49,0x49,0x49,0x31],
        'T': [0x01,0x01,0x7F,0x01,0x01],
        'U': [0x3F,0x40,0x40,0x40,0x3F],
        'V': [0x1F,0x20,0x40,0x20,0x1F],
        'W': [0x3F,0x40,0x38,0x40,0x3F],
        'X': [0x63,0x14,0x08,0x14,0x63],
        'Y': [0x07,0x08,0x70,0x08,0x07],
        'Z': [0x61,0x51,0x49,0x45,0x43],
        '0': [0x3E,0x51,0x49,0x45,0x3E],
        '1': [0x00,0x42,0x7F,0x40,0x00],
        '2': [0x42,0x61,0x51,0x49,0x46],
        '3': [0x21,0x41,0x45,0x4B,0x31],
        '4': [0x18,0x14,0x12,0x7F,0x10],
        '5': [0x27,0x45,0x45,0x45,0x39],
        '6': [0x3C,0x4A,0x49,0x49,0x30],
        '7': [0x01,0x71,0x09,0x05,0x03],
        '8': [0x36,0x49,0x49,0x49,0x36],
        '9': [0x06,0x49,0x49,0x29,0x1E],
        ':': [0x00,0x36,0x36,0x00,0x00],
        '-': [0x08,0x08,0x08,0x08,0x08],
        '%': [0x23,0x13,0x08,0x64,0x62],
    }

    def text(self, string, x, y, color=1):
        for ch in string.upper():
            glyph = self.FONT.get(ch, self.FONT[' '])
            for col_idx, col in enumerate(glyph):
                for row in range(8):
                    self.pixel(x + col_idx, y + row, (col >> row) & 1 if color else 0)
            x += 6
            if x > self.width:
                break

# Inicializa display
display = SSD1306(i2c)
display.fill(0)
display.text("CARRO", 30, 20)
display.text("BOMBEIRO", 16, 36)
display.show()
time.sleep(2)

# ========================
# SPI NRF24L01
# ========================
spi = SPI(0,
          baudrate=1000000,
          polarity=0,
          phase=0,
          sck=Pin(6),
          mosi=Pin(7),
          miso=Pin(4))
csn = Pin(5, Pin.OUT)
ce  = Pin(9, Pin.OUT)

# ========================
# ENDEREÇOS
# ========================
ADDR_CONTROLE = [0xE7,0xE7,0xE7,0xE7,0xE7]
ADDR_CARRO    = [0xC2,0xC2,0xC2,0xC2,0xC2]

# ========================
# DRIVER NRF24L01
# ========================
class NRF24:
    def __init__(self, spi, csn, ce):
        self.spi = spi
        self.csn = csn
        self.ce  = ce
        self.csn.value(1)
        self.ce.value(0)
        self.init_tx()

    def write_reg(self, reg, value):
        self.csn.value(0)
        self.spi.write(bytearray([0x20 | reg, value]))
        self.csn.value(1)

    def read_reg(self, reg):
        self.csn.value(0)
        self.spi.write(bytearray([reg & 0x1F]))
        result = self.spi.read(1)
        self.csn.value(1)
        return result[0]

    def set_addr(self, pipe_reg, addr_bytes):
        self.csn.value(0)
        self.spi.write(bytearray([0x20 | pipe_reg]) + bytearray(addr_bytes))
        self.csn.value(1)

    def flush_rx(self):
        self.csn.value(0)
        self.spi.write(bytearray([0xE2]))
        self.csn.value(1)

    def flush_tx(self):
        self.csn.value(0)
        self.spi.write(bytearray([0xE1]))
        self.csn.value(1)

    def init_tx(self):
        time.sleep_ms(100)
        self.write_reg(0x00, 0x0A)
        self.write_reg(0x01, 0x00)
        self.write_reg(0x02, 0x01)
        self.write_reg(0x05, 0x02)
        self.write_reg(0x06, 0x26)
        self.set_addr(0x10, ADDR_CARRO)
        self.set_addr(0x0A, ADDR_CONTROLE)
        self.write_reg(0x11, 4)
        self.flush_rx()
        self.flush_tx()
        self.write_reg(0x07, 0x70)

    def modo_rx(self):
        self.ce.value(0)
        self.write_reg(0x00, 0x0B)
        self.write_reg(0x02, 0x01)
        self.set_addr(0x0A, ADDR_CONTROLE)
        self.flush_rx()
        self.write_reg(0x07, 0x70)
        self.ce.value(1)
        time.sleep_us(150)

    def modo_tx(self):
        self.ce.value(0)
        self.write_reg(0x00, 0x0A)
        self.flush_tx()
        time.sleep_us(150)

    def send(self, data):
        self.modo_tx()
        self.csn.value(0)
        self.spi.write(bytearray([0xA0]) + data)
        self.csn.value(1)
        self.ce.value(1)
        time.sleep_us(15)
        self.ce.value(0)
        time.sleep_ms(3)
        self.write_reg(0x07, 0x70)
        self.modo_rx()

    def available(self):
        status = self.read_reg(0x07)
        if status & 0x10:
            self.write_reg(0x07, 0x70)
            self.flush_rx()
        return (status & 0x40) != 0

    def receive(self):
        self.csn.value(0)
        self.spi.write(bytearray([0x61]))
        data = self.spi.read(4)
        self.csn.value(1)
        self.write_reg(0x07, 0x40)
        return data

    def dump_regs(self):
        print("=== DUMP REGISTRADORES ===")
        print(f"CONFIG    (0x00): {self.read_reg(0x00):#04x}")
        print(f"EN_AA     (0x01): {self.read_reg(0x01):#04x}")
        print(f"EN_RXADDR (0x02): {self.read_reg(0x02):#04x}")
        print(f"RF_CH     (0x05): {self.read_reg(0x05):#04x}")
        print(f"RF_SETUP  (0x06): {self.read_reg(0x06):#04x}")
        print(f"STATUS    (0x07): {self.read_reg(0x07):#04x}")
        print(f"RX_PW_P0  (0x11): {self.read_reg(0x11):#04x}")
        self.csn.value(0)
        self.spi.write(bytearray([0x10]))
        tx_addr = self.spi.read(5)
        self.csn.value(1)
        print(f"TX_ADDR   (0x10): {[hex(b) for b in tx_addr]}")
        self.csn.value(0)
        self.spi.write(bytearray([0x0A]))
        rx0_addr = self.spi.read(5)
        self.csn.value(1)
        print(f"RX_ADDR_P0(0x0A): {[hex(b) for b in rx0_addr]}")
        print("==========================")

# ========================
# INICIALIZA RÁDIO
# ========================
radio = NRF24(spi, csn, ce)
print(">>> DUMP INICIAL (modo TX):")
radio.dump_regs()

# ========================
# FUNÇÕES
# ========================
def read_joystick(adc):
    return adc.read_u16()

def normalize(value):
    return int((value - 32768) / 32768 * 100)

# ========================
# LOOP PRINCIPAL
# ========================
INTERVALO_TX = 80
JANELA_RX    = 25

ultimo_tx = time.ticks_ms()

while True:

    if time.ticks_diff(time.ticks_ms(), ultimo_tx) >= INTERVALO_TX:

        x_norm = -normalize(read_joystick(joy1_x))
        y_norm = -normalize(read_joystick(joy1_y))

        btn = button.value()

        led.value(1 if btn == 0 else 0)

        # Determina status (AGUA se >= 30%, SECO abaixo)
        umidade_status = "AGUA" if umidade_atual >= 30 else "SECO"

        payload = bytearray([
            x_norm & 0xFF,
            y_norm & 0xFF,
            btn,
            0
        ])

        radio.send(payload)

        ultimo_tx = time.ticks_ms()

        deadline = time.ticks_add(time.ticks_ms(), JANELA_RX)
        recebeu  = False

        while time.ticks_diff(deadline, time.ticks_ms()) > 0:
            if radio.available():
                resp = radio.receive()
                if resp[2] == 0xFF:
                    print("RX OK | Umidade real:", resp[0])
                recebeu = True
                break
            time.sleep_ms(1)

        if not recebeu:
            print(f"Sem resposta RF | Umidade SIM: {umidade_atual}% [{umidade_status}]")

        # ---- Atualiza OLED ----
        display.fill(0)

        display.text("CARRO BOMBEIRO", 4, 0)

        display.text("X:" + str(x_norm), 0, 18)
        display.text("Y:" + str(y_norm), 0, 30)

        display.text(
            "BTN:" + ("ON" if btn == 0 else "OFF"),
            0, 42
        )

        display.text(
            "UM:" + str(umidade_atual) + "% " + umidade_status,
            0, 54
        )

        display.show()

    time.sleep_ms(1)

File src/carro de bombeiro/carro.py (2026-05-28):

from machine import Pin, SPI, PWM, ADC
import time

# ========================
# SPI NRF24L01
# ========================
spi = SPI(0,
          baudrate=1000000,
          polarity=0,
          phase=0,
          sck=Pin(6),
          mosi=Pin(7),
          miso=Pin(4))
csn = Pin(5, Pin.OUT)
ce  = Pin(12, Pin.OUT)

# ========================
# L298N - PONTE H
# ========================
in1 = Pin(0, Pin.OUT)
in2 = Pin(1, Pin.OUT)
ena = PWM(Pin(9))
ena.freq(1000)

in3 = Pin(2, Pin.OUT)
in4 = Pin(3, Pin.OUT)
enb = PWM(Pin(10))
enb.freq(1000)

in1.value(0)
in2.value(0)
in3.value(0)
in4.value(0)
ena.duty_u16(0)
enb.duty_u16(0)

# ========================
# BOMBA D'ÁGUA - GP8
# ========================
bomba = Pin(8, Pin.OUT)
bomba.value(0)

# LED indicador
led = Pin(13, Pin.OUT)

# ========================
# SENSOR DE UMIDADE
# ========================
umidade_analog  = ADC(Pin(27))
umidade_digital = Pin(22, Pin.IN)

FORA     = 60000
SUBMERSO = 10000

def ler_umidade():
    raw = sum(umidade_analog.read_u16() for _ in range(10)) // 10
    nivel = (FORA - raw) * 100 // (FORA - SUBMERSO)
    nivel = max(0, min(100, nivel))
    digital = 1 if umidade_digital.value() == 0 else 0
    return nivel, digital

# ========================
# ENDEREÇOS
# ========================
ADDR_CONTROLE = [0xE7,0xE7,0xE7,0xE7,0xE7]
ADDR_CARRO    = [0xC2,0xC2,0xC2,0xC2,0xC2]

# ========================
# DRIVER NRF24L01
# ========================
class NRF24:
    def __init__(self, spi, csn, ce):
        self.spi = spi
        self.csn = csn
        self.ce  = ce
        self.csn.value(1)
        self.ce.value(0)
        self.init_rx()

    def write_reg(self, reg, value):
        self.csn.value(0)
        self.spi.write(bytearray([0x20 | reg, value]))
        self.csn.value(1)

    def read_reg(self, reg):
        self.csn.value(0)
        self.spi.write(bytearray([reg & 0x1F]))
        result = self.spi.read(1)
        self.csn.value(1)
        return result[0]

    def set_addr(self, pipe_reg, addr_bytes):
        self.csn.value(0)
        self.spi.write(bytearray([0x20 | pipe_reg]) + bytearray(addr_bytes))
        self.csn.value(1)

    def flush_rx(self):
        self.csn.value(0)
        self.spi.write(bytearray([0xE2]))
        self.csn.value(1)

    def flush_tx(self):
        self.csn.value(0)
        self.spi.write(bytearray([0xE1]))
        self.csn.value(1)

    def init_rx(self):
        time.sleep_ms(100)
        self.write_reg(0x00, 0x0B)   # Power up + RX
        self.write_reg(0x01, 0x00)   # Sem auto-ack
        self.write_reg(0x02, 0x01)   # Pipe 0 habilitado
        self.write_reg(0x05, 0x02)   # Canal 2
        self.write_reg(0x06, 0x26)   # Data rate 1Mbps

        self.set_addr(0x0A, ADDR_CARRO)  # RX pipe 0 addr
        self.set_addr(0x10, ADDR_CONTROLE)  # TX addr (resposta)
        self.write_reg(0x11, 4)             # Payload pipe 0 = 4 bytes

        self.flush_rx()
        self.flush_tx()
        self.write_reg(0x07, 0x70)
        self.ce.value(1)

    def modo_tx(self):
        self.ce.value(0)
        self.write_reg(0x00, 0x0A)
        self.set_addr(0x10, ADDR_CONTROLE)  # TX aponta para o controle
        self.flush_tx()
        time.sleep_us(150)

    def modo_rx(self):
        self.ce.value(0)
        self.write_reg(0x00, 0x0B)
        self.set_addr(0x0A, ADDR_CARRO)
        self.flush_rx()
        self.write_reg(0x07, 0x70)
        self.ce.value(1)
        time.sleep_us(150)

    def available(self):
        status = self.read_reg(0x07)
        if status & 0x10:
            self.write_reg(0x07, 0x70)
            self.flush_rx()
        return (status & 0x40) != 0

    def receive(self):
        self.csn.value(0)
        self.spi.write(bytearray([0x61]))
        data = self.spi.read(4)
        self.csn.value(1)
        self.write_reg(0x07, 0x40)
        return data

    def send(self, data):
        self.modo_tx()
        self.csn.value(0)
        self.spi.write(bytearray([0xA0]) + data)
        self.csn.value(1)
        self.ce.value(1)
        time.sleep_us(20)
        self.ce.value(0)
        time.sleep_ms(5)
        self.write_reg(0x07, 0x70)
        self.modo_rx()

    def reset(self):
        self.ce.value(0)
        self.flush_rx()
        self.flush_tx()
        self.write_reg(0x07, 0x70)
        self.modo_rx()
        print("Radio reiniciado!")

# ========================
# FUNÇÕES DOS MOTORES
# ========================
def set_motor(in_a, in_b, en_pwm, speed):
    speed = max(-100, min(100, speed))
    if speed >= 10:
        in_a.value(1)
        in_b.value(0)
        en_pwm.duty_u16(int(speed / 100 * 65535))
    elif speed <= -10:
        in_a.value(0)
        in_b.value(1)
        en_pwm.duty_u16(int(abs(speed) / 100 * 65535))
    else:
        in_a.value(0)
        in_b.value(0)
        en_pwm.duty_u16(0)

def drive(x, y):
    motor_esq = max(-100, min(100, y + x))
    motor_dir = max(-100, min(100, y - x))
    set_motor(in1, in2, ena, motor_esq)
    set_motor(in3, in4, enb, motor_dir)

def parar():
    set_motor(in1, in2, ena, 0)
    set_motor(in3, in4, enb, 0)

# ========================
# INICIALIZA RÁDIO
# ========================
radio = NRF24(spi, csn, ce)
print("Receptor pronto, aguardando sinal...")
radio.modo_rx()  # Garantir RX mode ao iniciar

# Debug: mostrar config inicial
print(">>> CONFIG INICIAL (RX):")
print(f"CONFIG: {radio.read_reg(0x00):#04x} | EN_RX: {radio.read_reg(0x02):#04x} | CH: {radio.read_reg(0x05):#04x}")

# ========================
# LOOP PRINCIPAL
# ========================
TIMEOUT       = 500
TIMEOUT_RESET = 2000

ultimo_sinal  = time.ticks_ms()
primeiro_dump = True

while True:
    if radio.available():
        data = radio.receive()
        t0 = time.ticks_ms()

        y   = data[0] if data[0] < 128 else data[0] - 256
        x   = data[1] if data[1] < 128 else data[1] - 256
        btn = data[2]

        drive(x, y)
        bomba.value(1 if btn == 0 else 0)
        led.value(1)
        ultimo_sinal = time.ticks_ms()

        umid_pct, umid_dig = ler_umidade()
        t1 = time.ticks_ms()

        payload_umid = bytearray([
            umid_pct & 0xFF,
            umid_dig & 0xFF,
            0xFF,
            0
        ])

        radio.send(payload_umid)
        time.sleep_ms(50)  # Aumentado de 15ms → 50ms para garantir que resposta chega ao controle
        radio.modo_rx()    # Voltar para RX mode
        t2 = time.ticks_ms()

        print(f"X: {x} | Y: {y} | BOMBA: {1 if btn == 0 else 0} | "
              f"Nivel: {umid_pct}% | {'AGUA' if umid_dig == 1 else 'SECO'}")
        print(f"RESPOSTA_TX | Umidade: {umid_pct}% | Tempo ate envio: {time.ticks_diff(t1, t0)}ms | Total: {time.ticks_diff(t2, t0)}ms")

    if time.ticks_diff(time.ticks_ms(), ultimo_sinal) > TIMEOUT:
        parar()
        bomba.value(0)
        led.value(0)

    if time.ticks_diff(time.ticks_ms(), ultimo_sinal) > TIMEOUT_RESET:
        radio.reset()
        ultimo_sinal = time.ticks_ms()

    time.sleep_ms(10)

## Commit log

2026-05-07 model(controle): Modelagem da parte mecânica do controle
    [Controle Base.SLDPRT, Controle Tampa.SLDPRT]
2026-05-28 updt(codes): Carro e Controle
    [Barra dianteira.SLDPRT, Carro.SLDPRT, Carro.STL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]
2026-06-03 docs(final): final modifications on the documents
    [Tampa Controle.SLDPRT]
